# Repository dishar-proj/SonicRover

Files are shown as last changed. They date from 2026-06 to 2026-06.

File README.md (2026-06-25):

# Sonic Rover
Contributors: Disha Rachur, Emerson Hall, Zane Bush, Garv Bhumbla, Navangana Jha
Components: Raspberry Pi, H-Bridge, Motors, Chebychev Filters, Python

User Manual: https://dr43632.wixsite.com/my-site-3

The main objective of this project is to design a car that can detect and move to multiple fixed audio frequencies. Each team received a kit of parts to build an audio car. The design should prioritize cost-effective solutions to minimize financial strain. The team is free to utilize parts they buy with their own budget, however, if any component burns or gets damaged, the team is responsible for providing and paying for a new one. 

The design team is composed of five members. Garv Bhumbla (EE) is responsible for the hardware, power supply, and wiring components.  Zane Bush (EE) is responsible for operating the RP4 and looking over hardware to check functionality. Emerson Hall (CSE) is responsible for writing and debugging code, and monitoring the ADC. Navangana Jha (CSE) is responsible for checking and modifying the code if issues arise, and helps with documentation. Disha Rachur (CSE) is responsible for task organization, documentation, and some wiring. 

This project is organized into three major checkpoints. The first checkpoint requires the car to travel along a straight line path, square path, and a figure eight path. The second checkpoint consists of the car detecting the C8 frequency, moving towards it, and stopping. The final checkpoint requires the car to detect and move towards the C8 frequency and then detect the and move towards the C6 frequency. The first checkpoint is the minimum for a C, the second checkpoint is the minimum required for a B, and the third checkpoint is the minimum for an A-. Each week, teams will be assigned a progress deliverable or a design deliverable to add and refine the functionality of the audio car. The weekly tasks ensure that the group is able to work collaboratively toward project goals.

In addition to technical development, the project emphasizes teamwork and collaboration. CATME surveys were conducted throughout the duration of the project to assess team dynamics, address team issues, and enhance team efficiency.

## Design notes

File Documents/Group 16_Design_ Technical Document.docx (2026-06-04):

# Technical Documentation - Audio Car

Authors: Garv Bhumbla, Zane Bush, Emerson Hall, Navagana Jha, & Disha Rachur

## Table of Contents

1. Objective ………………………………………………………………….. 3
2. Constraints ………………………………………………………………… 5
3. Technical Design …………………………………………………….……. 7
  3.1. Hardware
  3.2. Software
  3.3. Power Supply
4. Ethics ………………………………………………………………………(2 pages)
  4.1. Design Originality
  4.2. Ethical Considerations
5. Self-critique ………………………………………………………………..(2 pages)
6. Revision Plan ………………………………………………………………(2 pages)
7. Individual Reflections ………………………………………………(½ page per member)
8. Appendix………………………………………………………………..#

## 1. Objectives

The main objective of this project is to create a working RC car that can recognize and move to multiple fixed audio frequencies. Each team received a kit of parts to utilize while designing the car. It is important to note that the objective of the design is to utilize inexpensive ideas so there is no financial strain. The team is free to utilize parts they buy with their own budget, however, if any component burns or gets damaged, it is the team’s responsibility to provide and pay for a new one.

Key Roles:

- Garv Bhumbla: Responsible for hardware, power supply and wiring components.
- Zane Bush: Responsible for operating the RP4, hardware, some code - involved in all areas.
- Emerson Hall: Handles most of the coding and testing code, operating RP4.
- Navagana Jha: Responsible for checking and modifying the code if issues arise, helps with documentation.
- Disha Rachur: Responsible for task organization/allocation, documentation, some coding, and some wiring.

## 2. Constraints

- What are the constraints, the boundary conditions for the project. Discuss these in such a way that you explain how they affected decisions made.
- The parts given to the group limited our ability on ways to power the car. We were able to utilize a 24V power supply to power the car. With limited voltage, we had to think of different ways that the car can be powered through the parts given such as transistors, op-amps, processors, convertors, and other items. With the 24 V that is given to us, we must design a way for the car to work throughout this voltage by distributing the voltage correctly.
- The car is required to draw figures. The three that our car will be tested on will be moving the car in a straight line, a square shape, and a figure 8 position. The next condition of this design requires the car to recognize a single sound frequency and be able to move towards it.
- All code must be written in Python and will be tested through the Raspberry pi.
- As we tested the functionality of our car, the motors were running into problems. Motor 2 kept falling off after running during our figure testing. For instance, after the robot created the square, the wheel started to come off causing issues. This showcases that the motors we were given can present a constraint as well.

## 3. Technical Design

### 3.1. Raspberry Pi

Make sure to put the SD card in the Raspberry Pi before connecting it to the monitor.

GPIO Diagram (https://docs.google.com/spreadsheets/d/1D65hbOhNtsgc8XrIhzrJAAzRHf0Px8tEgmuoeWSOSy4/edit?usp=sharing)

### 3.2. Git

If multiple people are working on the project at the same time, make sure to do a git pull before a git commit so you are committing changes to the most updated version of the project files.

### 3.3. H-Bridge & DC Motors

H-bridge in standalone mode: IC chip requires 5V for its internal logic, supplied from the pi hat, and the other Vcc powers the motors using an external power supply (we used the DC power supply to test standalone mode). We found that when a high signal was given to one of the odd input terminals on either side (pins 1A or 3A) the motor would turn counterclockwise and if the even input terminals were high (2A and 4A) the motor would turn clockwise. We observed that both motors moved at different speeds but increasing voltage generally caused them both to speed up. To change input signals, we would simply take a 5V line coming from a power supply to one of the input terminals and connect it to the other causing a change in direction. If both input terminals on either side of the H-bridge were the same (both high or both low) that motor would not run at all.

Transfer function: A range of 5.0V(minimum voltage required) - 12.0V (max voltage supplied by power supply) was used to collect RPM data using the code RPMcalculator.py. After recording RPMs, voltage (x-axis) vs. RPM (y-axis) and used a line of best fit to find the slope of the two curves (one for each motor). The graphs are displayed in Figure 1.3 and Figure 1.4 below. The best fit line equations for each motor are y = 41.044x - 83.809 and y = 42.240x - 82.75 with the slope representing K for each motor.

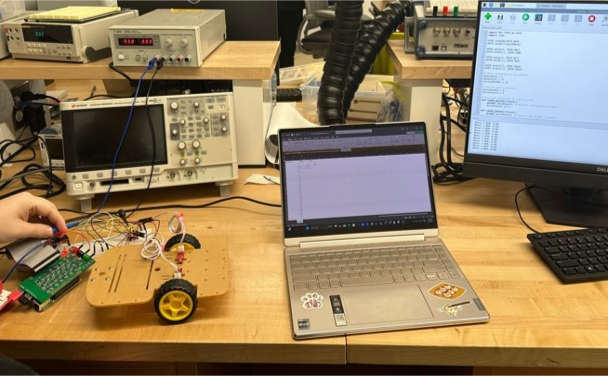
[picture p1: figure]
Inserting image...

Figure 1.1: Calculations obtained to derive the transfer function. | Figure 1.2: Experimental Setup for RPM.

These are the values based on the newest calculations performed after switching out a faulty motor. In our initial characterization, we found that the car swerved to the left, however, the motor pin values for the motors were switched which caused this issue, after verifying the motors, the car moved straight. Here are videos of the car traveling in a straight line: (https://drive.google.com/file/d/12Vc6abKyclVbozORSefFgr8AAUDDyFzG/view?usp=sharing)StraightCar1 (https://drive.google.com/file/d/12Vc6abKyclVbozORSefFgr8AAUDDyFzG/view?usp=sharing) and (https://drive.google.com/file/d/1xnOPEoM0LvMKnCauP7OUr1QQfUS1K948/view?usp=sharing)StraightCar2. (https://drive.google.com/file/d/1xnOPEoM0LvMKnCauP7OUr1QQfUS1K948/view?usp=sharing)

### 3.4. Power Supply

Simulation of push-pull amplifier: Referenced designs can be found in Appendix Section A.1.

Using Multisim, the circuit at Figure 1.1 was simulated using 10K ohm resistors. For this initial circuit, two positive voltages (2.374 V and 21.289 V) were achieved. Following additional research, it was noted (Figure A.1.2.1) the 24V source was in parallel with the entire branch with the diodes and resistors. Using the design in Figure 1.2, a positive and negative voltage on each end was achieved (-9.78 V and 14.50 V). To achieve voltages to be +/- 12V, different resistors were used to experiment with adding resistors between the two transistors, and on the different legs of the transistors; however, the correct voltages were not achieved. After further experimentation and removing the third resistor in the bottom leg of the bottom MOSFET, using 10K resistors for both the resistances, and verifying that we used the point between the two resistors as our virtual ground (we were originally using the point in between the two transistors), we were able to get +/- 12V. However, when adding loads, the voltages become unstable so +/- 12V were not maintained. After further research, it was found multiple push-pull amplifier designs incorporated op-amps. Using an op-amp assists the MOSFETs operate with their optimal range, as the negative feedback improves stability and can help with phase splitting. Inserting resistors in between the MOSFETs helped to stabilize the voltage, however, resistance values that were too high such as 10k and 5k ohms limited the current flow to the MOSFET gates since the resistors are connected to the feedback loop of the op-amps, so 10 ohms and 5 ohms were used.

### 3.5. Microphones

Characterize microphone:

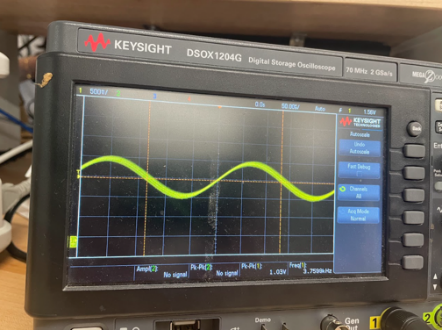
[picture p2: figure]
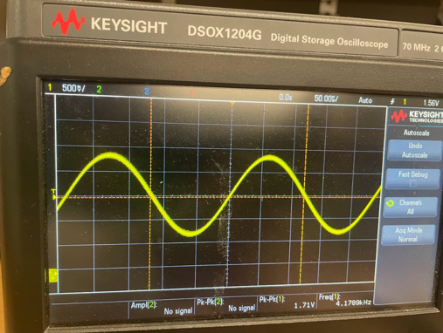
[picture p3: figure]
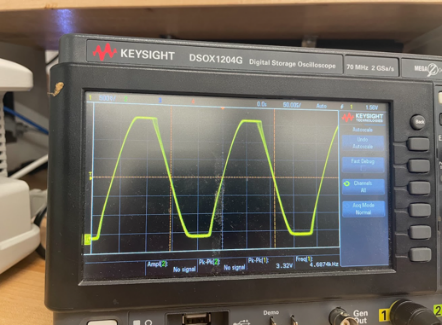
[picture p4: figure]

Figure 3: Output for 3686 Hz | Figure 4: Output for 4186 Hz | Figure 5: Output for 4686 Hz

We found for all these values; the microphone measured a similar frequency in our output reading. However, we observed that when input frequencies were less than 500 Hz and more than 9 kHz, they would begin to become inaccurate and unstable. This does not concern us because, as stated above, these frequencies are out of scope for this project. When testing our gain increase on the microphone, we discovered that an increase in gain would also increase the output voltage of the microphone and allow it to pick up sounds that were further away from the microphone. When our gain was low, we would have to essentially rest our phones on the microphone to pick up sounds but when gain was increased the source could be slightly further away. Similar results were achieved for both microphones, so it can be concluded that both the microphones are functional and similar in behavior.

[General Notes - will eventually be deleted]

- This is the main section of the document. It should contain multiple subchapters fully describing all aspects of the design: hardware and software.
- Yes, this also includes your power supply. We recommend a separate subsection for this in the Technical Design part of the document.
- You may reference work from your prior submissions. You will want to “clean up” the work and use the key parts in the write up. You will also need to reference the file so we can find it (week, name of file, etc...)
- You may use snippets of your software’s primary code where needed. Otherwise reference your code with information to find it (file name, line numbers, etc....)
- Do not describe reference material here. If you did not design it, but are referring to it, put it in the appendix.

## 4. Ethics

- What did your team do to ensure that your design was your own
- If this design was truly for a product used by others, what would your group need to ethically consider? (Note, you may want to review the Engineer’s code of ethics https://www.nspe.org/resources/ethics/code-ethics).

## 5. Self-critique

- How did the team perform based on your results and your expectations? Consider different aspects: teamwork, hardware, software, whatever you think is important to your critique. Note, critiques can discuss good and not-so-good things.

## 6. Revision Plan

- Based on your results, describe changes that your team could make with respect to design choices, methods, etc... to improve the design if you had time for another iteration.
- Describe what might be different if this were a real product versus a class project.

## 7. Individual Reflections

- Each person independently writes a self-reflection on the project

## 8. Appendix

- You may provide links to main reference materials (specifications)
- If you watched a video or referred to a website, you must reference it in the main part of the document and provide the link in the Appendix.
- Use the Appendix for other items that your team finds necessary and important. Do not use the appendix as a “spam” location for all kinds of material.
- Separate the Appendix into meaningful sections: A.1, A.2, A.3, for example

A.1: Push-Pull Amplifier to split 24VDC into -12VDC an 12VDC

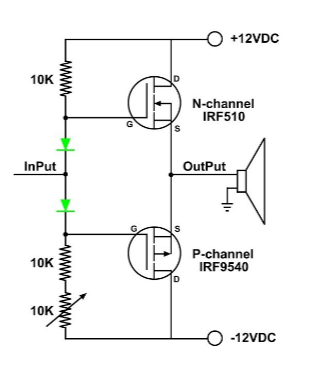
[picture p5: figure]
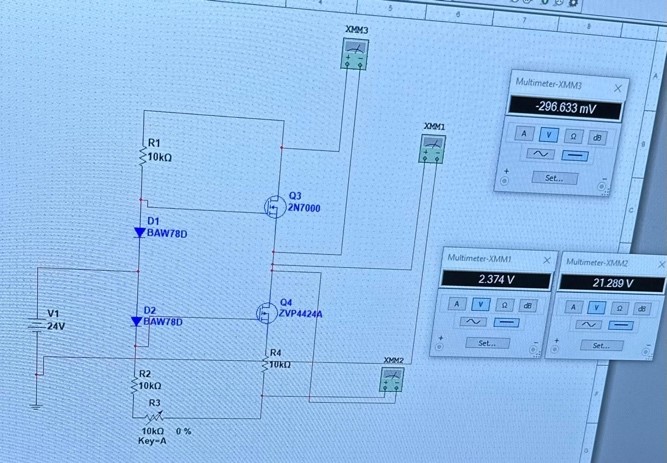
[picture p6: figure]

Figure 1.1: Design 1 – Inspiration and Multisim implementation

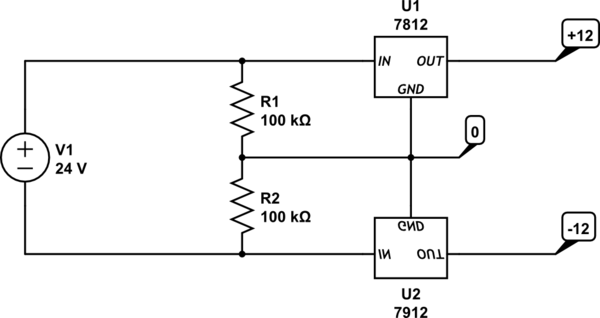
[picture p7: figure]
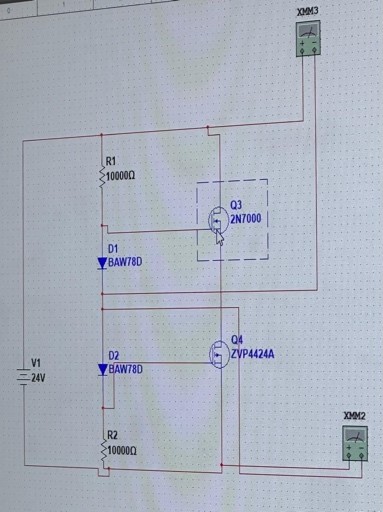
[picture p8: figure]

Figure 1.2: Design 2 – Inspiration and Multisim implementation

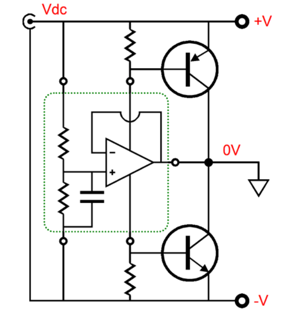
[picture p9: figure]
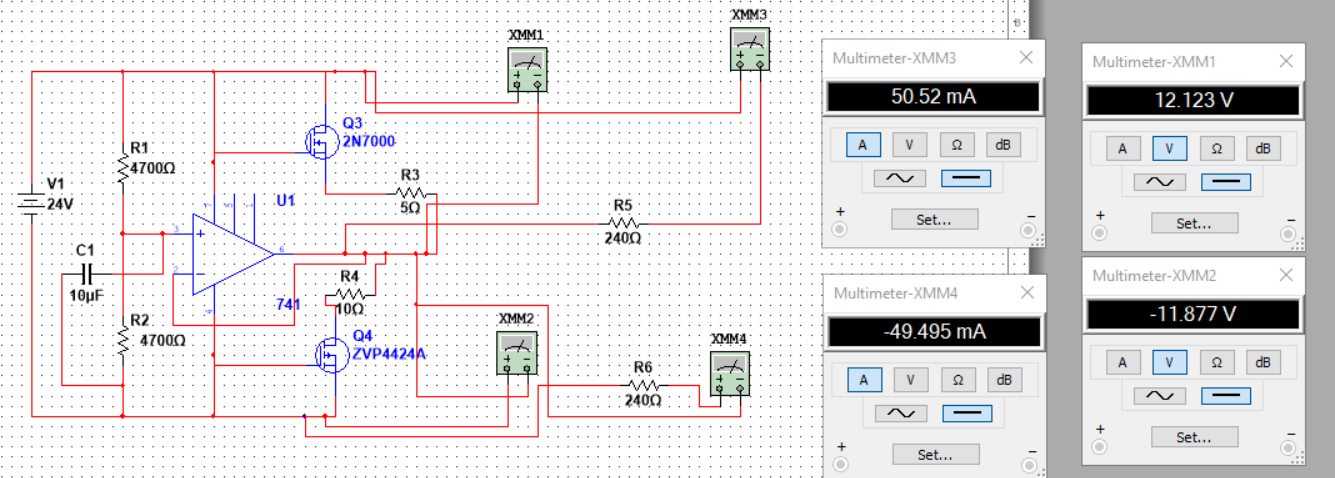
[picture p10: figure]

Figure 1.3: Design 3 – Inspiration and Multisim implementation with loads

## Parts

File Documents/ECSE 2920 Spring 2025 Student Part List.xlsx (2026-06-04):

1. General Parts
Part | Comments | Quantity | Student Replace | Link |  | Have
Dupont Wires | FF,FM,MM | 120 (40 each) | Return |  |  | Y
Wire Jumper kit |  | 1 | Return |  |  | Y
Breadboard kit (Rexquails) |  | 1 | Return | https://www.amazon.com/Breadboards-Solderless-Breadboard-Distribution-Connecting/dp/B07DL13RZH |  | Y
GPIO Breakout with ribbon cable |  | 1 | Yes | https://www.amazon.com/KEYESTUDIO-GPIO-Breakout-Kit-Raspberry/dp/B072XBX3XX?adgrpid=1335907984533349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 |  | Y
24V Power Supply |  | 1 | Yes | https://www.amazon.com/ALITOVE-100-240V-Adapter-Converter-5-5x2-1mm/dp/B01GC6VS8I?adgrpid=1344703291437725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 |  | **will get soon
Jack Adapter |  | 1 | Yes | https://www.amazon.com/Ksmile%C2%AE-Female-2-1x5-5mm-Adapter-Connector/dp/B015OCV5Y8 |  | Y
Adafruit Auto Gain Mic |  | 2 | Yes | https://www.adafruit.com/product/1063 |  | Y
Quad H-Bridge | SN754410 or L293 | 1 | Yes | Find on Digikey |  | Y
Switch Chip | 8 switches | 1 |  |  |  | Y
Bump Switch |  | 2 |  |  |  | Y
Quad Comparator | LM339 | 2 |  |  |  | Y
Optical Encoders (sensor) |  | 2 | Yes | https://www.amazon.com/HESAI-Printer-Mechanical-Optical-Makerbot/dp/B0719K9Z9R |  | Y
Optical Encoder (wheel) |  | 2 | Yes | https://www.amazon.com/Chironal-50pcs-Coded-Encoder-Sensor/dp/B07G4BDFHH |  | Y
Quad Op Amp | TL084 | 4 |  |  |  | Y
PCB Standoffs |  | kit |  |  |  | Y
IC Sockets |  | 4 |  |  |  | Y
IRF4905 | P Channel Mosfet | 1 |  | https://www.amazon.com/BOJACK-IRF4905-Transistors-IRF4905S-P-Channel/dp/B0854CG2DQ?adgrpid=1345802904377710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 |  | Y
IRFZ34 | N Channel Mosfet | 1 |  | https://www.amazon.com/Bridgold-IRFZ34N-IRFZ34-N-Channel-Transistor/dp/B07TVJWXPQ |  | Y
4N25 | Optoisolator | 1 |  | https://www.jameco.com/z/4N25-James-Electronics-Optocoupler-NPN-Out-1-Channel-5300Vrms-30V-DIP-6_40985.html |  | Y
Shunt Resistor |  | Student supplied |  |  |  | -----
LED Assortment |  | 6 |  |  |  | Y
Stripboard |  | Optional |  | https://www.amazon.com/ELEGOO-Prototype-Soldering-Compatible-Arduino/dp/B072Z7Y19F |  | Y
Assortment of Capacitors | Kit will be placed in fab lab |  |  |  |  | ------
Buck converter |  |  |  |  |  | Y
 |  |  |  |  |  | DO NOT HOT PLUG YOUR RASPBERRY PY
2. Audio Car Kit Parts |  |  |  |  |  | TURN IT OFF BEFORE YOU PLUG OR UNPLUG
Part | Quantity | Student Replacement | Link |  | Park Check
Audio Car Kit | 1 | Yes | https://www.amazon.com/perseids-Chassis-Encoder-Wheels-Battery/dp/B07DNYQ3PX
Back Wheels | 2 |  | https://www.amazon.com/Smart-Chassis-Motors-Encoder-Battery/dp/B01LXY7CM3?s=toys-and-games |  | Y
Front Wheel | 1 |  | https://www.amazon.com/perseids-Chassis-Encoder-Wheels-Battery/dp/B07DNYQ3PX |  | Y
Chassis | 1 | Let us know if it breaks | Chassis updated using Sendcutsend.com |  | Y
DC Motors | 2 | Yes | https://www.amazon.com/dp/B07P9ZSWBG |  | Y
Wires | 4 |  |  |  | Y
Battery Holder | 1 |  |  |  | Y
motor fastners | 4 |  |  |  | Y
Long screws | 4 |  |  |  | Y
Spacers | 4 |  |  |  | Y
Small Screws | 11 |  |  |  | Y
Nuts | 9 |  |  |  | Y
Switch | 1 |  |  |  | Y
3. Canakit Parts
Part | Quantity | Student Replace | Link |  | Part Check
Raspberry Pi 4 (4GB) | 1 | Yes | https://www.canakit.com/raspberry-pi-4-basic-kit.html |  | Y
Micro HDMI | 1 | Yes | https://www.canakit.com/raspberry-4-mico-hdmi-cable.html |  | Y
Heat sinks | 3 | Yes | https://www.canakit.com/raspberry-pi-4-heat-sinks.html |  | Y
USB MicroSD Card Reader | 1 | Yes | https://www.canakit.com/mini-micro-sd-usb-reader.html |  | Y
32GB MicroSD Card | 1 | Yes | https://www.amazon.com/SanDisk-Extreme-microSDHC-UHS-3-SDSQXAF-032G-GN6MA/dp/B06XWMQ81P |  | Y
PI On/Off Switch | 1 | Yes | https://www.amazon.com/LoveRPi-MicroUSB-Switch-Raspberry-Female/dp/B018BFWLRU |  | Y
Pi Power Supply | 1 | Yes | https://www.amazon.com/CanaKit-Raspberry-Power-Supply-USB-C/dp/B07TYQRXTK |  | Y
Raspberry Pi Mouse | Optional | Yes | https://www.canakit.com/official-raspberry-pi-keyboard-mouse.html
Raspberry Pi Keyboard | Optional | Yes | https://www.canakit.com/official-raspberry-pi-keyboard-mouse.html |  | Y

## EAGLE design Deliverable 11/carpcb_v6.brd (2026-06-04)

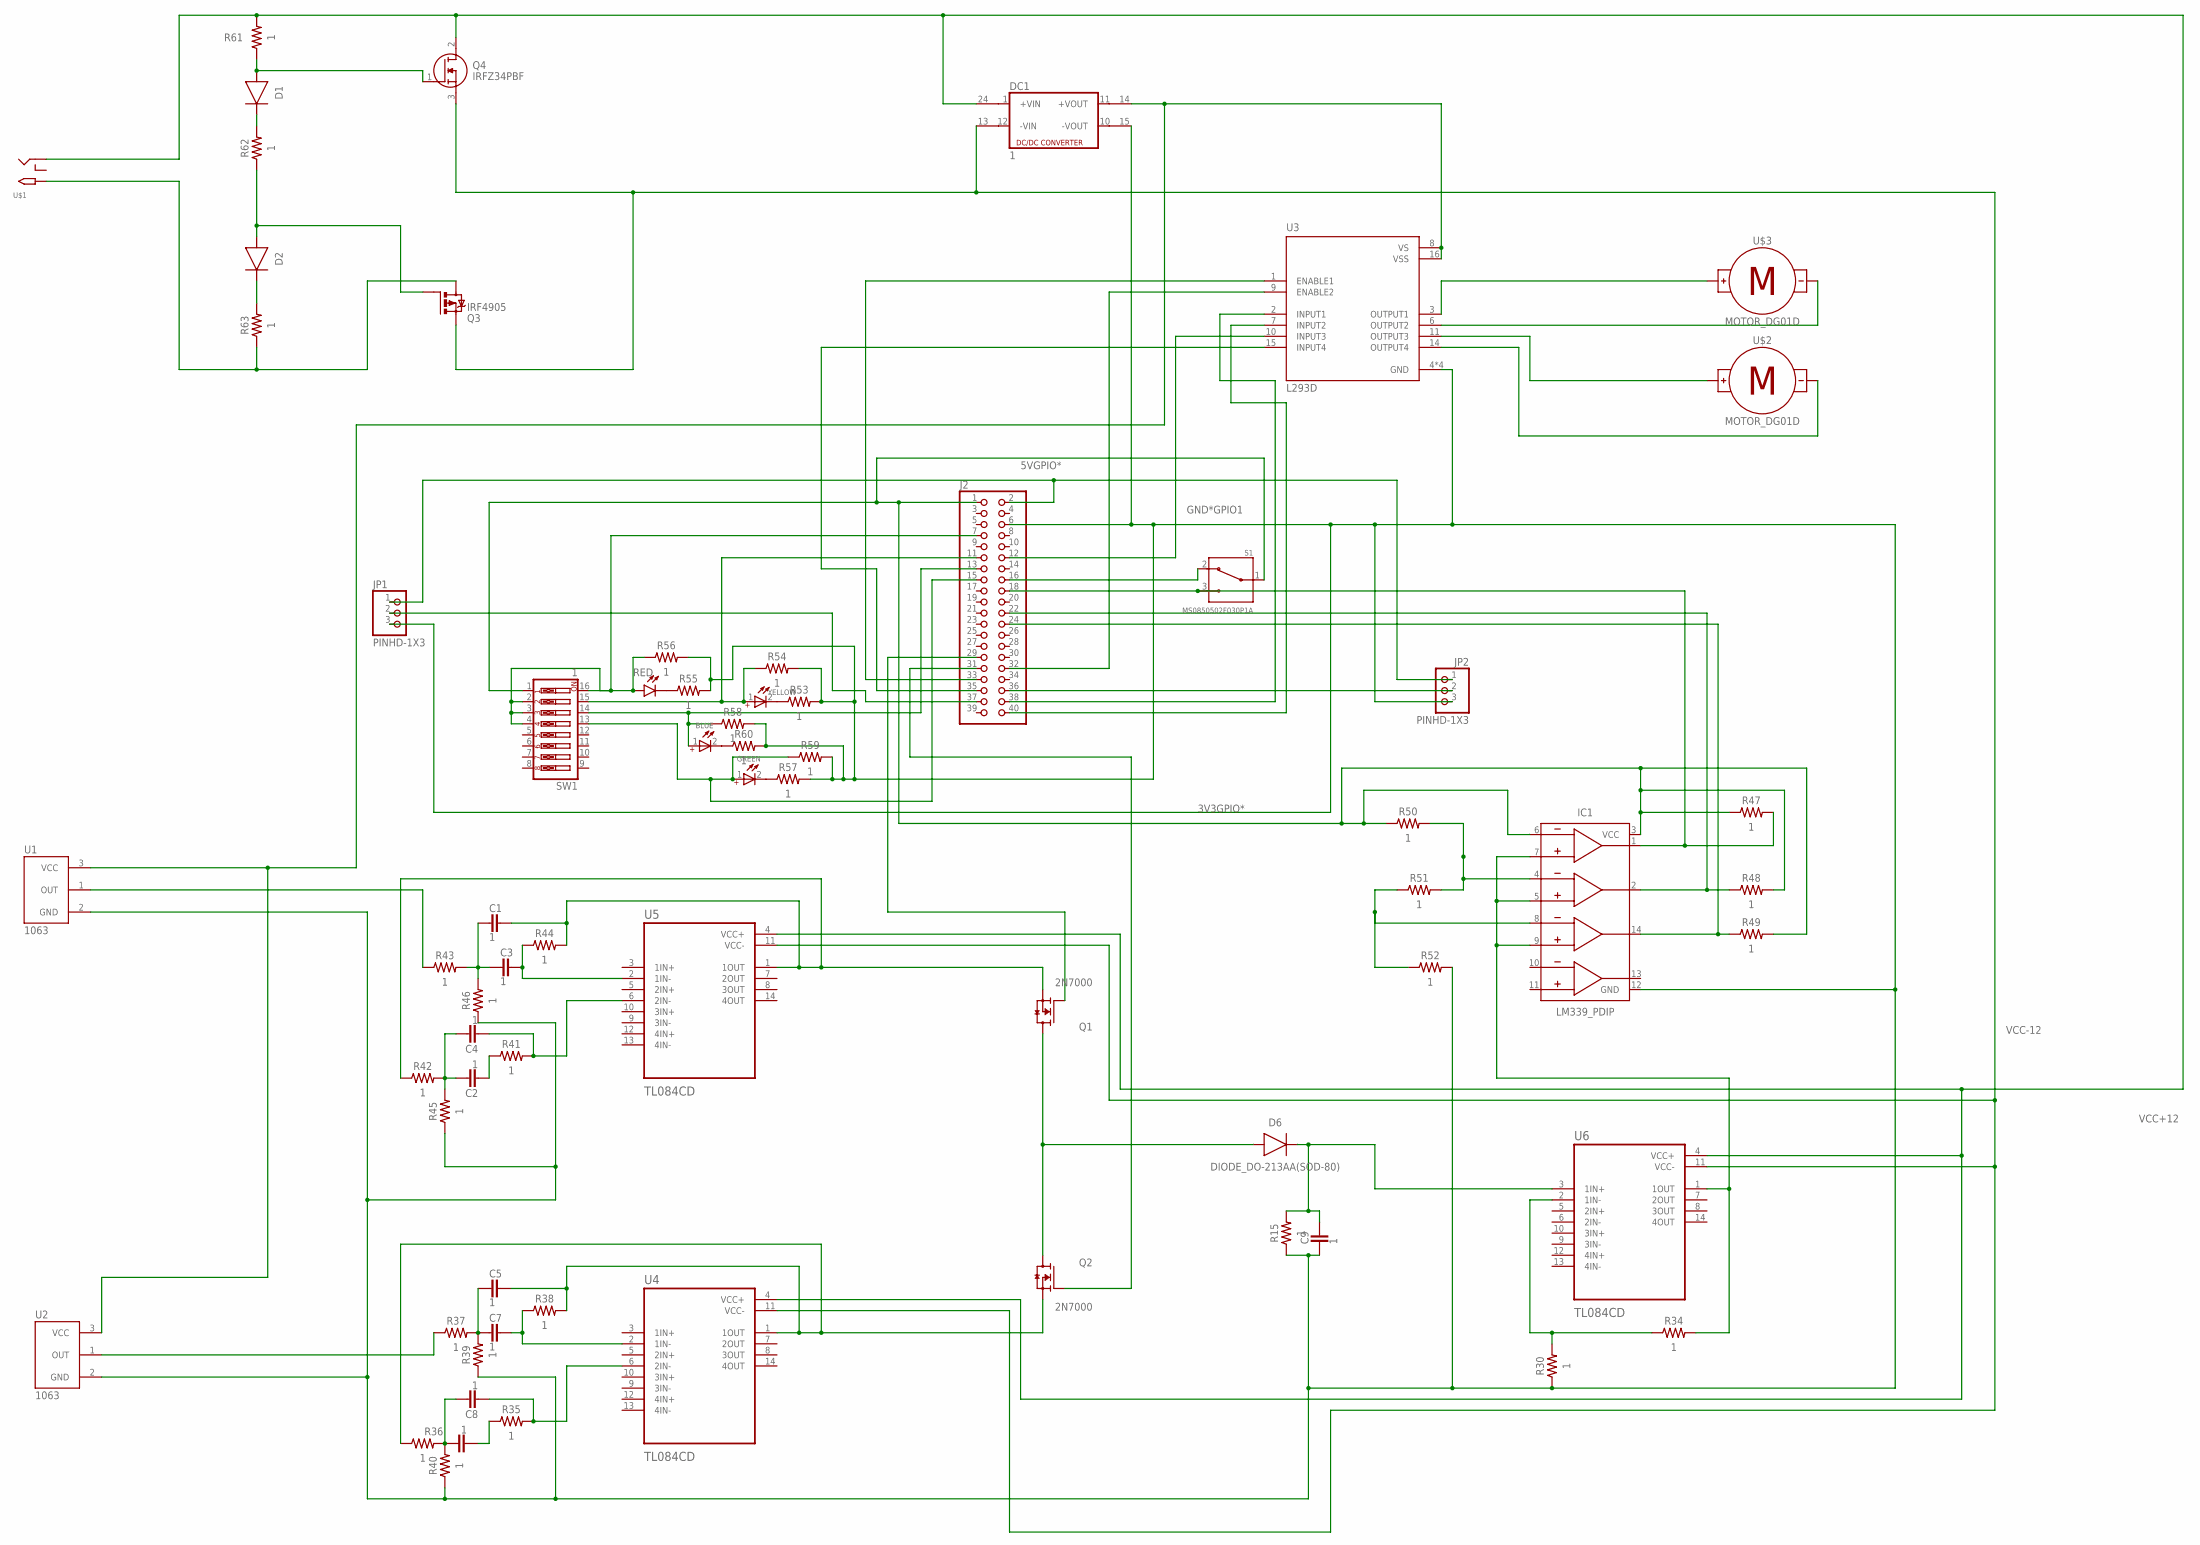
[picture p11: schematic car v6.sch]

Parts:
BLUE: WL-TMRC_5MM_WITHOUTSTOPPER; WL-TMRC_5MM
C1, C2, C3, C4, C5, C6, C7, C8, C9: 1; CAPC1005X60
D1, D2, D6: DIODE_DO-213AA(SOD-80); DIOMELF3516
DC1: 1; CMK
GREEN: WL-TMRC_3MM_WITHOUTSTOPPER; WL-TMRC_3MM
IC1: LM339_PDIP; DIP762W53P254L1969H508Q14B
J2: PiHeaderM; 2X20
JP1, JP2: PINHD-1X3; 1X03
Q1, Q2: 2N7000; TO92254P458H750-3
Q3: IRF4905; TO220BH
Q4: IRFZ34PBF; TO254P465X1024X2050-3P
R15, R30, R34, R35, R36, R37, R38, R39, R40, R41, R42, R43, R44, R45, R46, R47, R48, R49, R50, R51, R52, R53, R54, R55, R56, R57, R58, R59, R60, R61, R62, R63: 1; RESC1005X40
RED: LED_RADIALRED; LEDRD254W60D565H860B_R
S1: MS0850502F030P1A; SW_MS0850502F030P1A
SW1: 1; EDG-08
U1, U2: 1063; MODULE_1063
U3: L293D; DIP880W50P254L2000H510Q16
U4, U5, U6: TL084CD; SOIC127P600X175-14N
U$1: 2.1MMJACKTHM; PJ-102A
U$2, U$3: MOTOR_DG01D; DG01D
YELLOW: WL-TMRC_3MM_WITHOUTSTOPPER; WL-TMRC_3MM

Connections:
3V3GPIO*: IC1.3 (VCC), IC1.6 (-IN1), J2.1, R47.1, R48.2, R49.2, R50.1, S1.1 (COM), SW1.1
5VGPIO*: J2.2, JP1.1, JP2.1
GND*GPIO1: C9.2, DC1.15 (-VOUT1), IC1.12 (GND), J2.6, JP1.3, JP2.3, R15.1, R30.1, R39.1, R40.1, R45.1, R46.1, R52.2, R53.2, R54.2, R55.2, R56.2, R57.2, R58.2, R59.2, R60.2, U1.2 (GND), U2.2 (GND), U3.4 (GND), U3.5 (GND), U3.12 (GND), U3.13 (GND)
GPIO4*: J2.7, R56.1, RED.A, SW1.2, SW1.3, SW1.4, SW1.16
GPIO5*: J2.29, Q1.2 (G)
GPIO6*: J2.31, Q2.2 (G)
GPIO8*: IC1.14 (OUT3), J2.24, R49.1
GPIO12*: J2.32, U3.9 (ENABLE2)
GPIO13*: J2.33, U3.1 (ENABLE1)
GPIO16*: J2.36, JP2.2
GPIO17*: J2.11, R54.1, SW1.15, YELLOW.1 (+)
GPIO18*: J2.12, U3.10 (INPUT3)
GPIO19*: J2.35, U3.15 (INPUT4)
GPIO20*: J2.38, U3.2 (INPUT1)
GPIO21*: J2.40, U3.7 (INPUT2)
GPIO22*: GREEN.1 (+), J2.15, R59.1, SW1.13
GPIO23*: J2.16, S1.2 (NC)
GPIO24*: IC1.1 (OUT1), J2.18, R47.2, S1.3 (NO)
GPIO25*: IC1.2 (OUT2), J2.22, R48.1
GPIO26*: J2.37, JP1.2
GPIO27*: BLUE.1 (+), J2.13, R58.1, SW1.14
unnamed: D1.2 (A), Q4.1 (G), R61.1
unnamed: D1.1 (C), R62.2
unnamed: D2.2 (A), Q3.G, R62.1
unnamed: D2.1 (C), R63.2
unnamed: Q3.D, R63.1, U$1.TIP
unnamed: U3.11 (OUTPUT3), U$2.+
unnamed: U3.3 (OUTPUT1), U$3.+
unnamed: C1.2, C3.2, R43.2, R46.2
unnamed: DC1.14 (+VOUT1), U1.3 (VCC), U2.3 (VCC), U3.8 (VS), U3.16 (VSS)
unnamed: C3.1, R44.1, U5.2 (1IN-)
unnamed: C2.1, C4.1, R42.2, R45.2
unnamed: C2.2, R41.1
unnamed: C1.1, Q1.1 (S), R42.1, R44.2, U5.1 (1OUT)
unnamed: C4.2, R41.2, U5.6 (2IN-)
unnamed: R55.1, RED.C
unnamed: R43.1, U1.1 (OUT)
unnamed: C5.2, C7.2, R37.2, R39.2
unnamed: C7.1, R38.1, U4.2 (1IN-)
unnamed: C6.1, C8.1, R36.2, R40.2
unnamed: C6.2, R35.1
unnamed: C5.1, Q2.1 (S), R36.1, R38.2, U4.1 (1OUT)
unnamed: C8.2, R35.2, U4.6 (2IN-)
unnamed: R53.1, YELLOW.2 (-)
unnamed: R37.1, U2.1 (OUT)
unnamed: C9.1, D6.1 (C), R15.2, U6.3 (1IN+)
unnamed: GREEN.2 (-), R57.1
unnamed: D6.2 (A), Q1.3 (D), Q2.3 (D)
unnamed: BLUE.2 (-), R60.1
unnamed: IC1.4 (-IN2), R50.2, R51.2
unnamed: IC1.8 (-IN3), R51.1, R52.1
unnamed: U3.6 (OUTPUT2), U$3.-
unnamed: R30.2, R34.1, U6.2 (1IN-)
unnamed: IC1.5 (+IN2), IC1.7 (+IN1), IC1.9 (+IN3), R34.2, U6.1 (1OUT)
unnamed: U3.14 (OUTPUT4), U$2.-
VCC+12: DC1.24 (+VIN1), Q4.2 (D), R61.2, U4.4 (VCC+), U5.4 (VCC+), U6.4 (VCC+), U$1.RING
VCC-12: DC1.13 (-VIN1), Q3.S, Q4.3 (S), U4.11 (VCC-), U5.11 (VCC-), U6.11 (VCC-)

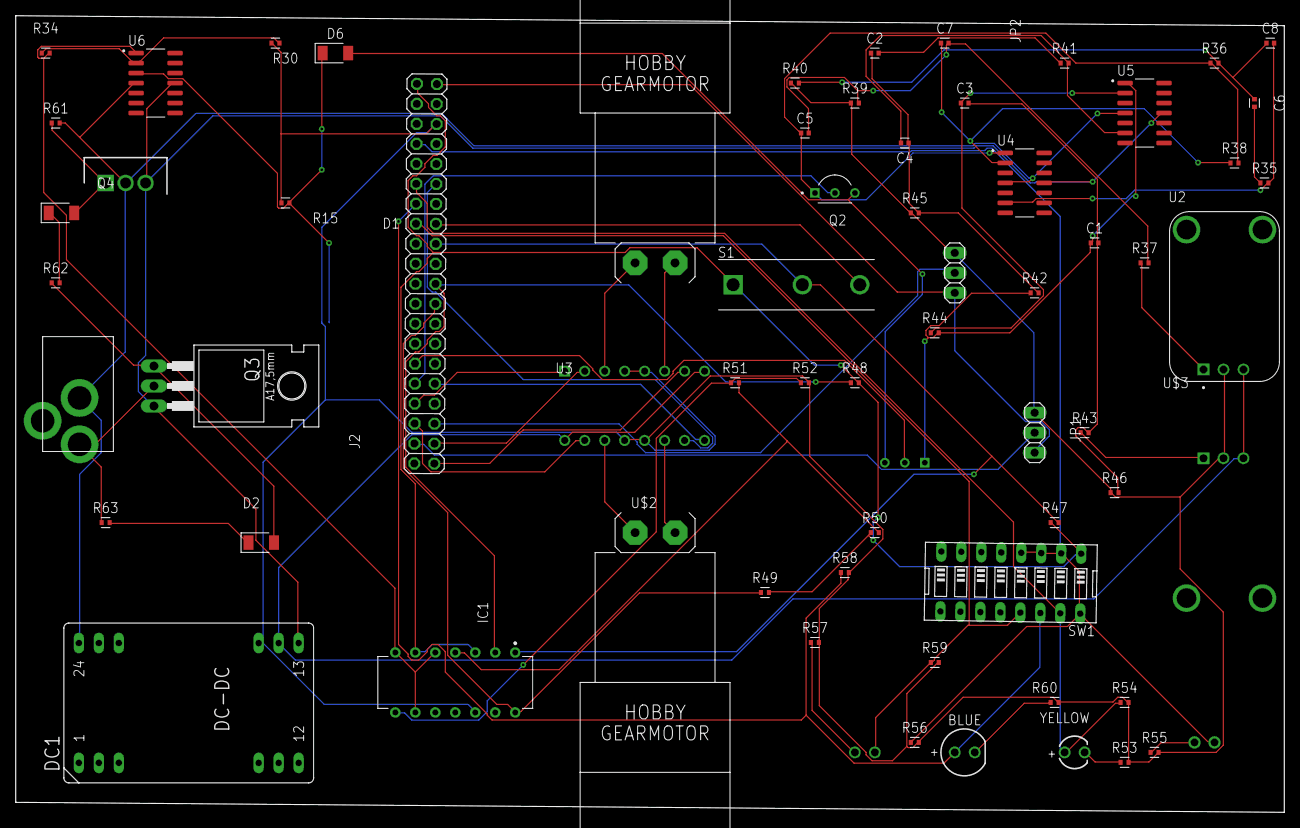
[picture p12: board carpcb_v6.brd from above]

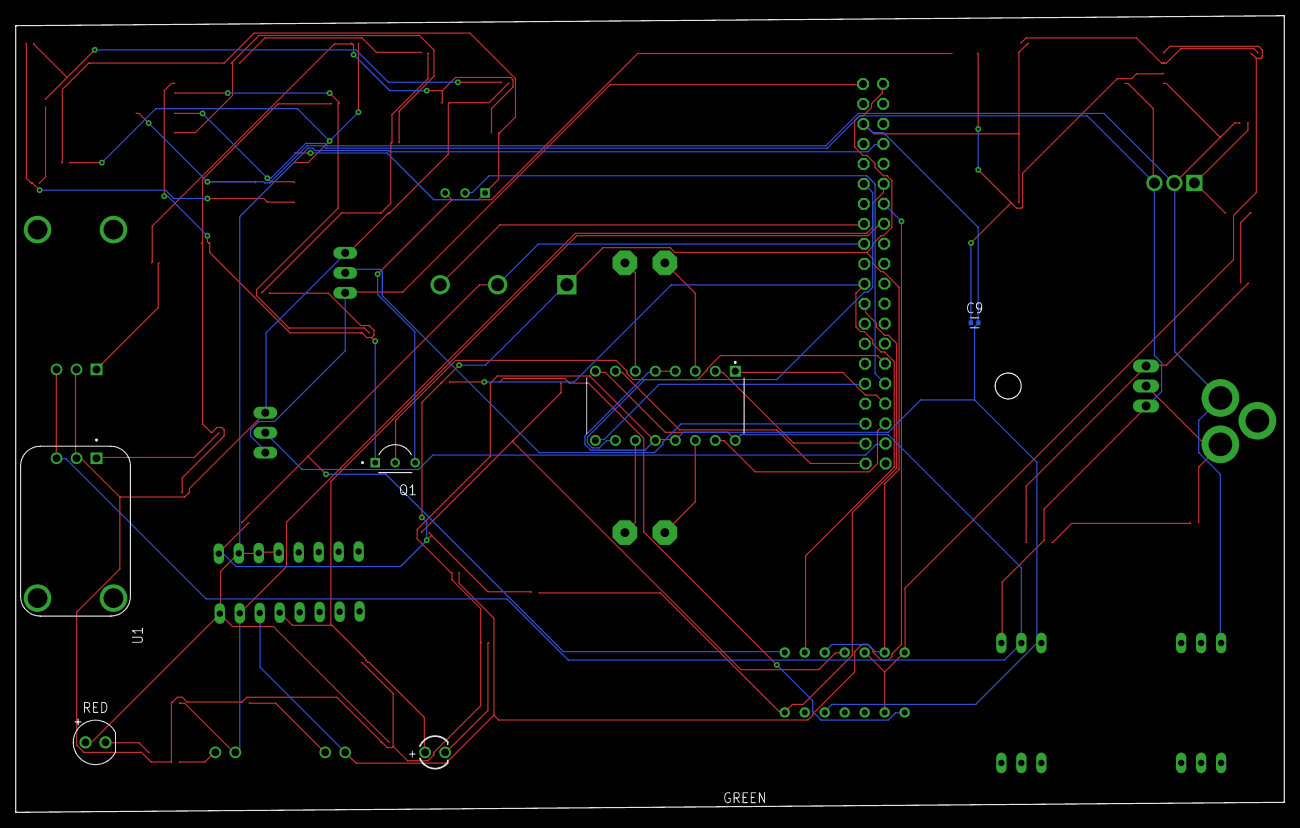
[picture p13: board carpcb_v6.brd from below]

Board: 2 copper layers, 161.3 x 101.3 mm, 68 parts (6 on the bottom side), 57 nets.

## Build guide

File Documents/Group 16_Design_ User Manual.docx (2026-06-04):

# User Manual - Audio Car

Authors: Garv Bhumbla, Zane Bush, Emerson Hall, Navangana Jha, & Disha Rachur

## Table of Contents

1. Safety Information …………………………………………………………….3
2. Step-by-Step Guide ……………………………………………………………#
3. Troubleshooting ……………………………………………………………….#
4. FAQs …………………………………………………………………………..#
5. Further Resources………………………………………………………………#

## 1. Safety Information

It is important to note that the audio car contains many electrical components. Be sure to plug in the car properly while the raspberry pi (RP4) is not on. Do not touch or unplug the wires while the car is on and plugged into the power supply. DO NOT HOTPLUG the Raspberry Pi.

## 2. Step-by-Step Guide

  a. Power
    i. First, plug in the Raspberry Pi 4 with its personal power supply and wait for the LEDs of the Raspberry Pi to turn on.
    ii. Then, connect the buck converter of the car (the green and black piece that is on the top of the car) to the 24V power supply.
    iii. The car should be on.
    iv. If the car is not working, disconnect and contact the manufacturers.
  b. Figure Drawing with the car
    i. Switch 1 sets a mode for the specific design. With the car and the Raspberry Pi 4 powered, the switch can be set to control the motion of the car.
    ii. The LEDs correspond with the switches to signal that it is on: switch 1 - red, switch 2 - yellow, switch 3 - blue, switch 4 - green.
    iii. After setting the car to a mode, the car waits 3 seconds before starting.
    iv. The mode will not start until switch 1 is flipped. Make sure to flip switch 1 last as it is an ON/OFF switch..
    v. Raspberry Pi and power supply must be plugged in and wires must not be pulling on the car for the functions to work
  c. Figure Drawing Settings

Switches | LEDs lit | Operation
1, 2 | Red, Yellow | Travel in a 3-foot-long straight line
1, 2, 3 | Red, Yellow, Blue | Travel in a square shape twice
1, 2, 4 | Red, Yellow, Green | Travel in a figure 8 twice

## 3. Troubleshooting

  a. If the modes are not working, hold the cords over the car.

## 4. FAQs

## 5. Further Resources

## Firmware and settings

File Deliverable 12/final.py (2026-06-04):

# Group 16
# Authors: Emerson Hall and Disha Rachur and Navi Jha

# import statements
import RPi.GPIO as GPIO
import time

# Set GPIO mode
GPIO.setmode(GPIO.BCM)
GPIO.setwarnings(False)

# Motor Pins
motor1_in1 = 20
motor1_in2 = 7
motor2_in1 = 18
motor2_in2 = 19
enable_motor1 = 13  # Enable pin 1
enable_motor2 = 12  # Enable pin 2

# ADC
comp1_output = 24 # MSB
comp2_output = 25  # Middle bit
comp3_output = 8  # LSB

# Bump Switch
bump_switch_pin = 23  # Bump switch pin (adjust as needed)

# Filter Control Pins
filter_C8 = 5
filter_C6 = 6
GPIO.setup(filter_C8, GPIO.OUT)
GPIO.setup(filter_C6, GPIO.OUT)
GPIO.output(filter_C8, GPIO.LOW)
GPIO.output(filter_C6, GPIO.LOW)

# Set up comparator output pins as input
GPIO.setup(comp1_output, GPIO.IN)
GPIO.setup(comp2_output, GPIO.IN)
GPIO.setup(comp3_output, GPIO.IN)

# Bump Switch Set up
GPIO.setup(bump_switch_pin, GPIO.IN, pull_up_down=GPIO.PUD_UP)

# Set up DIP switch pins as input
GPIO.setup(4, GPIO.IN)
GPIO.setup(17, GPIO.IN)
GPIO.setup(27, GPIO.IN)
GPIO.setup(22, GPIO.IN)

# Set up motor control pins as output
GPIO.setup(motor1_in1, GPIO.OUT)
GPIO.setup(motor1_in2, GPIO.OUT)
GPIO.setup(motor2_in1, GPIO.OUT)
GPIO.setup(motor2_in2, GPIO.OUT)
GPIO.setup(enable_motor1, GPIO.OUT)
GPIO.setup(enable_motor2, GPIO.OUT)

# PWM Setup
pwm_motor1 = GPIO.PWM(enable_motor1, 100)
pwm_motor2 = GPIO.PWM(enable_motor2, 100)
pwm_motor1.start(0)
pwm_motor2.start(0)

# Function to control motors (direction and speed)
def control_motor(direction_motor1, direction_motor2, speed_motor1, speed_motor2):
    GPIO.output(motor1_in1, GPIO.HIGH if direction_motor1 == 1 else GPIO.LOW)
    GPIO.output(motor1_in2, GPIO.LOW if direction_motor1 == 1 else GPIO.HIGH)
    GPIO.output(motor2_in1, GPIO.HIGH if direction_motor2 == 1 else GPIO.LOW)
    GPIO.output(motor2_in2, GPIO.LOW if direction_motor2 == 1 else GPIO.HIGH)
    pwm_motor1.ChangeDutyCycle(speed_motor1)
    pwm_motor2.ChangeDutyCycle(speed_motor2)

# Read states of comparators and convert to 3-bit ADC value
def read_adc():
    comp1_state = GPIO.input(comp1_output)  # MSB (bit 2)
    comp2_state = GPIO.input(comp2_output)  # Middle bit (bit 1)
    comp3_state = GPIO.input(comp3_output)  # LSB (bit 0)
    
    # Combine the bits into a 3-bit number (binary to integer)
    adc_value = (comp1_state << 2) | (comp2_state << 1) | comp3_state
    
    return adc_value

# Read bump switch state
def is_bump_switch_pressed():
    return GPIO.input(bump_switch_pin) == GPIO.LOW  # LOW when pressed

# Move forward for a given time
def move_forward(time_to_move):
    control_motor(1, 1, 100, 77.5)  # Move both motors forward
    time.sleep(time_to_move + 0.8)
    control_motor(0, 0, 0, 0)  # Stop motors
    time.sleep(0.1)

# Reverse Movement
def move_backward(time_sec):
    control_motor(0, 0, 100, 90) # Move backwards
    time.sleep(-(time_sec))
    control_motor(0, 0, 0, 0) # Stop mmotors
    time.sleep(0.1)

# Rotate 90 degrees in place (adjust timing as needed)
def turn_right():
    control_motor(1, 0, 100, 0)  # Motor 1 forward, Motor 2 stopped
    time.sleep(0.8)  # Adjust this time to achieve a 90-degree turn
    control_motor(0, 0, 0, 0)  # Stop motors
    time.sleep(0.1)

# Rotate for figure 8 
def turn_right8():
    control_motor(1, 1, 100, 30)  # Motor 1 forward, Motor 2 slow
    time.sleep(3.9)  # Adjust this time to achieve an arch turn
    control_motor(0, 0, 0, 0)  # Stop motors

# Make a left turn (~120 degrees for a curved path)
def turn_left8():
    control_motor(1, 1, 40, 100)  # Motor 1 slow, Motor 2 forward
    time.sleep(3.1)  # Adjust this time for a smoother left arch turn
    control_motor(0, 0, 0, 0)  # Stop motors
    time.sleep(1)

# Function to calculate the time to move a certain distance
def move_distance(feet):
    wheel_diameter = 0.062  # Wheel diameter in meters (62 mm)
    wheel_circumference = 3.1416 * wheel_diameter  # Circumference in meters
    motor1_rpm = 135  # Motor 1 RPM at 5V
    motor2_rpm = 126  # Motor 2 RPM at 5V
    meters_per_minute1 = (motor1_rpm * wheel_circumference) / 60
    meters_per_minute2 = (motor2_rpm * wheel_circumference) / 60
    distance_meters = feet * 0.3048  # Convert feet to meters
    time_to_move = distance_meters / min(meters_per_minute1, meters_per_minute2)
    if feet > 0:
        move_forward(time_to_move)
    else:
        move_backward(time_to_move)

# Move in a square pattern
def move_square():
    for _ in range(4):
        move_distance(3)  # Move forward 3 feet
        time.sleep(1)
        turn_right()  # Turn 90 degrees
        time.sleep(1)
        move_distance(3)  # Move forward 3 feet
        time.sleep(1)
        turn_right()  # Turn 90 degrees
        time.sleep(1)

# Move in a figure-8 pattern
def move_figure_8():
    for _ in range(2):  # Complete the figure-8 twice
        move_distance(3)  # Move forward 3 feet
        turn_right8()  # Turn right
        move_distance(3)  # Move forward 3 feet
        turn_left8()  # Turn right

# Single Sound Behavior - When ADC detects a value of 111 (sound detected)
def single_sound_behavior():
    while True:
        # Read ADC
        GPIO.output(5, GPIO.HIGH)
        GPIO.output(6, GPIO.LOW)
        adc_value = read_adc()
        
        # Read ADC and turn left
        if adc_value == 0b000:
            print("ADC: {} - Turning Left (Normal Speed)".format(bin(adc_value)))
            control_motor(1, 0, 90, 0)  # Left turn (normal speed)
        
        # Read the ADC and turn slower
        elif adc_value == 0b001:
            print("ADC: {} - Turning Left (Slower)".format(bin(adc_value)))
            control_motor(1, 0, 80, 0)  # Slower left turn
        
        # Read the ADC and turn slowest
        elif adc_value == 0b011:
            print("ADC: {} - Slowing Down Even More but Still Turning Left".format(bin(adc_value)))
            control_motor(1, 0, 70, 0)  # Even slower left turn
        
        # Read the ADC value to detect the sound
        elif adc_value == 0b111:
            print("ADC: {} - Stopping to Confirm".format(bin(adc_value)))
            control_motor(0, 0, 0, 0)  # Stop
            time.sleep(0.5)  # Small delay before rechecking
            
            # Reread the ADC to confirm
            if read_adc() == 0b111:
                print("ADC: {} - Confirmed. Moving Forward".format(bin(adc_value)))
                while not is_bump_switch_pressed(): # Detect the bump switch
                    control_motor(1, 1, 100, 90)
                    time.sleep(0.1)
                print("Bump switch activated! Stopping.")
                GPIO.output(5, GPIO.LOW)
                break
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

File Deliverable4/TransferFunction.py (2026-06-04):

# Import Statements
import RPi.GPIO as GPIO
import time

# Set GPIO mode
GPIO.setmode(GPIO.BCM)
# Set Warnings to False
GPIO.setwarnings(False)

# Define GPIO pins connected to the L293D motor driver
motor1_in1 = 20
motor1_in2 = 21
motor2_in1 = 18
motor2_in2 = 19 
enable_motor1 = 13  # Enable pin for motor 1 (PWM)
enable_motor2 = 12  # Enable pin for motor 2 (PWM)

# Setup the GPIO pins
GPIO.setup(motor1_in1, GPIO.OUT)
GPIO.setup(motor1_in2, GPIO.OUT)
GPIO.setup(motor2_in1, GPIO.OUT)
GPIO.setup(motor2_in2, GPIO.OUT)
GPIO.setup(enable_motor1, GPIO.OUT) # Controls the speed of the motor
GPIO.setup(enable_motor2, GPIO.OUT) # Controls the speed of the motor

# Initialize PWM for motor speed control
pwm_motor1 = GPIO.PWM(enable_motor1, 100)  # 100 Hz frequency for PWM
pwm_motor2 = GPIO.PWM(enable_motor2, 100)
pwm_motor1.start(0)  # Start with 0% duty cycle (motor off)
pwm_motor2.start(0)  # Start with 0% duty cycle (motor off)

# Transfer function constants for each motor
K1 = 41.044  # Gain for motor 1
K2 = 42.24  # Gain for motor 2
tau = 0.000125  # Time constant for both motors
dt = 0.1  # Time step (seconds)

# Initialize motor speeds (RPM)
rpm_motor1 = 0
rpm_motor2 = 0

# Discrete-time model of the transfer function (1st order)
def update_motor_speed(voltage, motor_num):
    """Update motor speed using the transfer function (discrete-time model)"""
    if motor_num == 1:
        K = K1
    else:
        K = K2

    # Discrete-time update of the transfer function
    motor_speed = (K / tau) * voltage * dt + rpm_motor1  # Using same logic for both motors
    return motor_speed

# Function to control motor direction and speed
def control_motor(direction_motor1, direction_motor2, speed_motor1, speed_motor2):
    # Motor 1 direction
    if direction_motor1 == 1:
        # Forward
        GPIO.output(motor1_in1, GPIO.HIGH)
        GPIO.output(motor1_in2, GPIO.LOW)
    else:
        # Backward
        GPIO.output(motor1_in1, GPIO.LOW)
        GPIO.output(motor1_in2, GPIO.HIGH)

    # Motor 2 direction
    if direction_motor2 == 1:
        # Forward
        GPIO.output(motor2_in1, GPIO.HIGH)
        GPIO.output(motor2_in2, GPIO.LOW)
    else:
        # Backward
        GPIO.output(motor2_in1, GPIO.LOW)
        GPIO.output(motor2_in2, GPIO.HIGH)

    # Set PWM duty cycle to control speed
    pwm_motor1.ChangeDutyCycle(speed_motor1)
    pwm_motor2.ChangeDutyCycle(speed_motor2)

# Main loop
try:
    while True:
        # Example desired voltage for both motors (same control voltage for both)
        control_voltage = 6  # Example control voltage in volts (adjust as needed)

        # Simulate the motor speed using the transfer function for both motors
        rpm_motor1 = update_motor_speed(control_voltage, 1) # Motor 1
        rpm_motor2 = update_motor_speed(control_voltage, 2) # Motor 2

        # Convert motor speeds to PWM duty cycle (0-100 scale)
        speed_motor1 = min(max((rpm_motor1 / 300) * 100, 0), 100)
        speed_motor2 = min(max((rpm_motor2 / 300) * 100, 0), 100)

        # Assume forward direction for both motors
        direction_motor1 = 1
        direction_motor2 = 1

        # Control both motors to run at the same speed
        control_motor(direction_motor1, direction_motor2, speed_motor1, speed_motor2)

        time.sleep(dt)  # Update every 100 ms

except KeyboardInterrupt:
    pwm_motor1.stop() # End
    pwm_motor2.stop() # End
    GPIO.cleanup() # Clears the pins
    
